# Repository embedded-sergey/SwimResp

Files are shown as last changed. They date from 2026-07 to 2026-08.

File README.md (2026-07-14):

# SwimResp
SwimResp is a pump and motor speed controller for swim tunnels used to perform Ucrit measurements.  It also interfaces with the PyroScience Pico‑OEM module to transmit optical dissolved‑oxygen and temperature data over USB to a PC for logging during intermittent‑flow aquatic respirometry workflows.

It is part of the FishResp project (more information at https://fishresp.org).

## Build Guide
The complete assembly, wiring, calibration, and safety instructions are provided in: `docs/SwimResp_Build_Guide.md`

This README intentionally avoids duplicating the Build Guide.

## Licensing
SwimResp uses a multi‑license structure:

- **Hardware designs:** CERN‑OHL‑S v2  
- **Software:** GPL‑3.0  
- **Documentation:** CC‑BY‑4.0  

Mixed‑content files (e.g., documentation containing schematics or code snippets) are governed by the license of each component.

See the **LICENSE** file for the human‑readable overview and the `LICENSES/` directory for full legal texts.

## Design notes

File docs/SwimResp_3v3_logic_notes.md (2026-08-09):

# SwimResp 3.3 V‑logic notes  
SwimResp can operate with 3.3 V‑logic Nano‑family boards (Nano 33 BLE, Nano 33 IoT, RP2040, Nano ESP32), which may provide additional functionality.

This topic is outside the scope of the main build guide. Several design and assembly adjustments are required, and the list below reflects unverified considerations only.

1. All SwimResp components (status LED, push button, L298N motor driver board, OLED display, Pico‑O2 OEM logger) operate correctly at 3.3 V logic level.

2. Power the OLED display from the 3.3 V pin of a 3.3 V‑logic Arduino Nano to ensure reliable two‑way I²C communication.

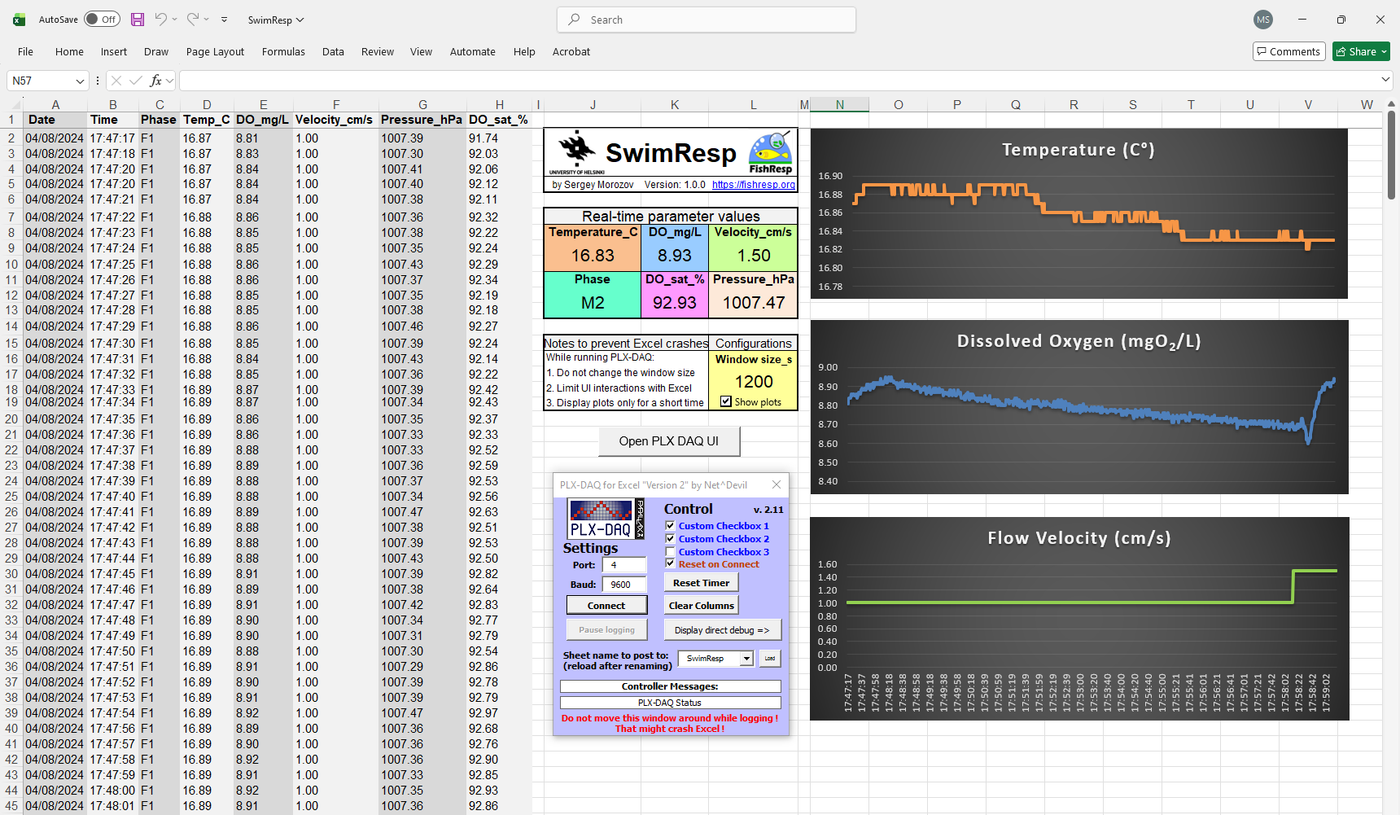
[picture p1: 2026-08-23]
docs/images/SwimResp_screenshot.png

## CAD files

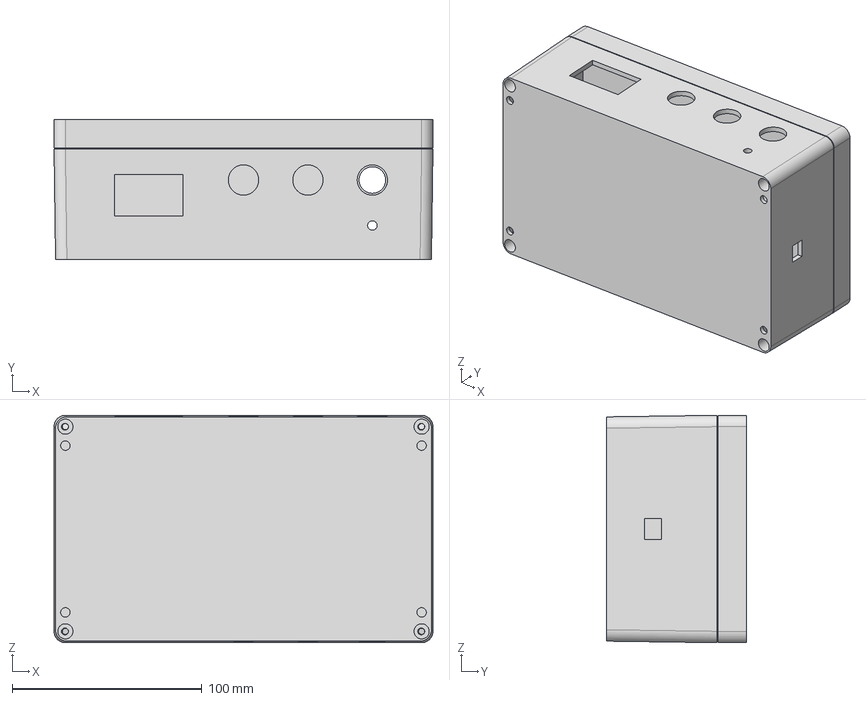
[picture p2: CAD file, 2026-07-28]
hardware/cad/SwimResp_enclosure_assembly.step
200.0 x 74.0 x 120.0 mm

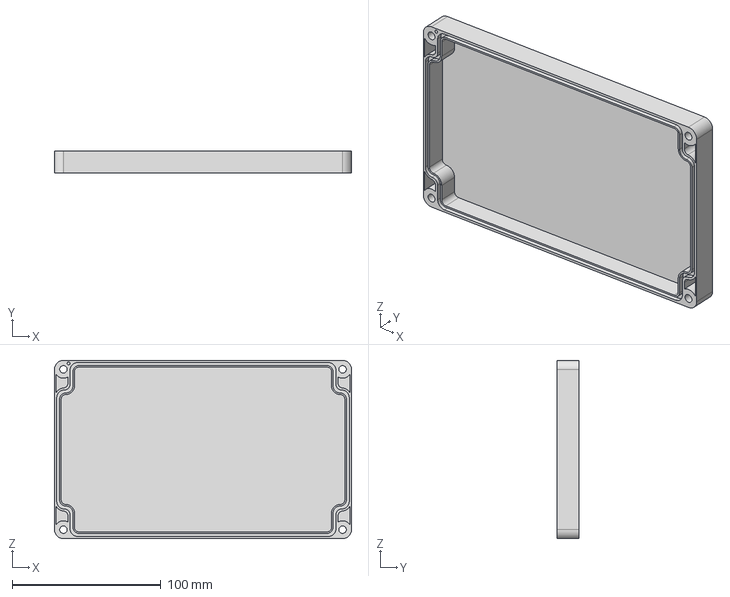
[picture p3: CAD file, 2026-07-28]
hardware/cad/SwimResp_enclosure_cover.step
200.0 x 15.0 x 120.0 mm

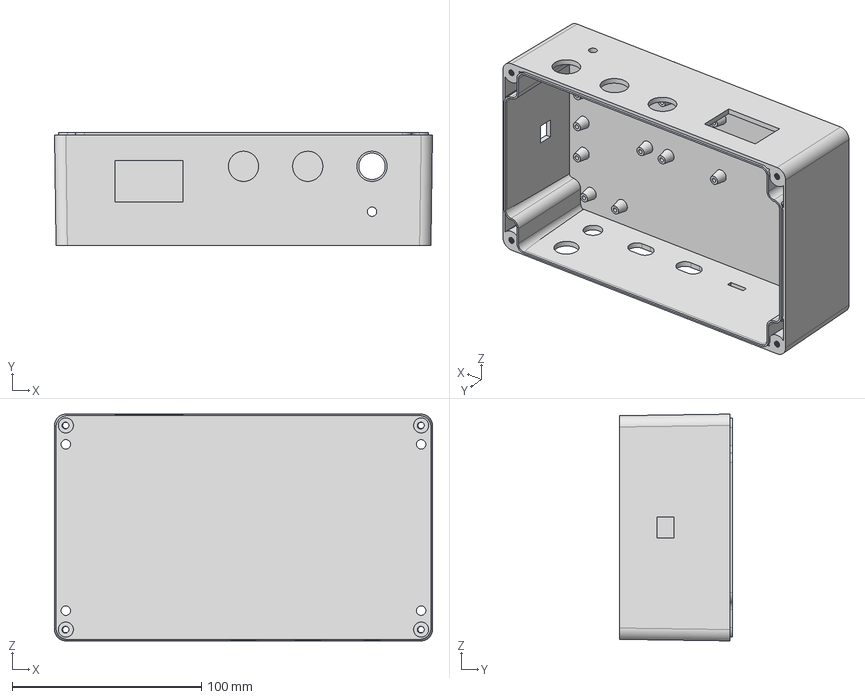
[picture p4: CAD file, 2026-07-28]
hardware/cad/SwimResp_enclosure_base.step
200.0 x 60.0 x 120.0 mm

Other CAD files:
hardware/stl/SwimResp_enclosure_base.stl
hardware/stl/SwimResp_enclosure_cover.stl

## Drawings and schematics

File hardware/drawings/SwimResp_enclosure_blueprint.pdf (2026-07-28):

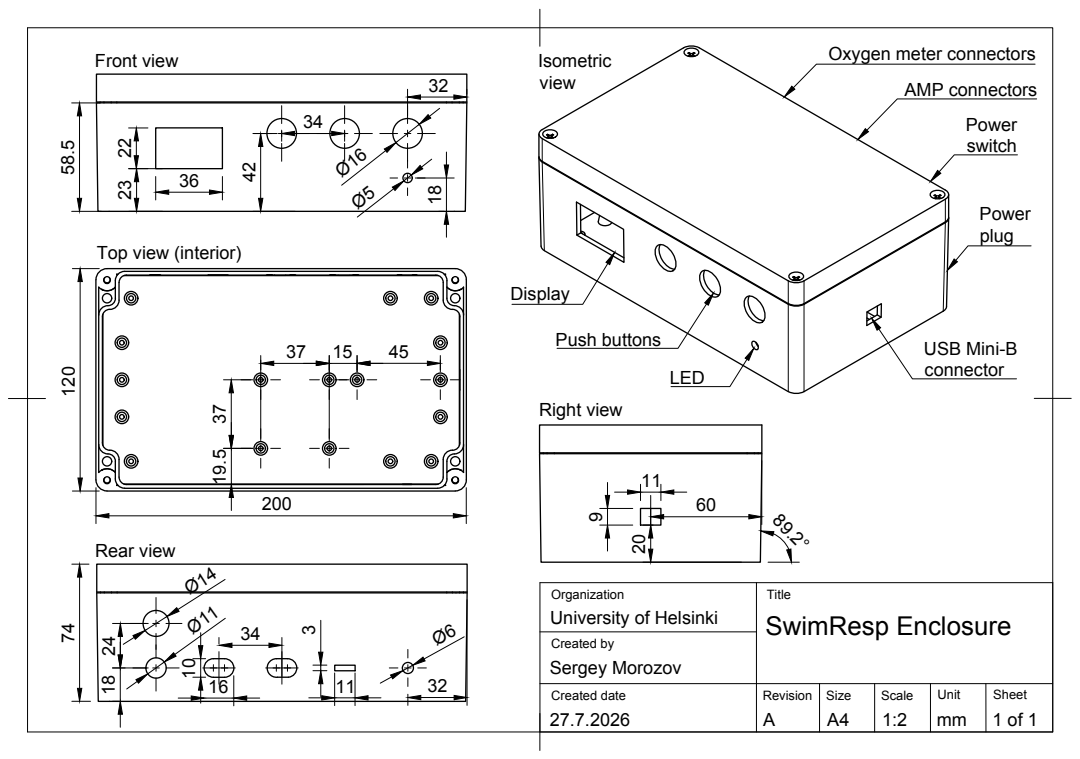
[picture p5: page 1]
Created by; Created date; Revision; Size; Scale; SwimResp Enclosure; Sergey Morozov; USB Mini-B; Push buttons; AMP connectors; Rear view; Right view

Oxygen meter connectors Front view

Top view (interior)

University of Helsinki

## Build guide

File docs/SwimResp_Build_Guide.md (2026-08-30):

---
title: "SwimResp Build Guide"
author: "Sergey Morozov"
date: "30 August 2026"
revision: "0.6"
toc: true
toc-depth: 3
---

# SwimResp Build Guide
**Revision:** 0.6
**Author:** Sergey Morozov  
**Date:** 30 August 2026

<!-- begin-md-image -->
SwimResp Device
<!-- end-md-image -->

# Table of Contents

1. [Introduction](#1-introduction)
2. [Safety Notes](#2-safety-notes)  
   2.1 [Environmental Safety](#21-environmental-safety)  
   2.2 [Electrical Safety](#22-electrical-safety)  
   2.3 [Mechanical and Tool Safety](#23-mechanical-and-tool-safety)
3. [Bill of Materials](#3-bill-of-materials)
4. [Tools and Consumables](#4-tools-and-consumables)
5. [Assembly Instructions](#5-assembly-instructions)  
   5.1 [Preparing the enclosure](#51-preparing-the-enclosure)  
   5.2 [Installing power distribution components](#52-installing-power-distribution-components)  
   5.3 [Installing and wiring the controller](#53-installing-and-wiring-the-controller)  
   5.4 [Adding the user interface components](#54-adding-the-user-interface-components)  
   5.5 [Connecting the DO and temperature logger](#55-connecting-the-do-and-temperature-logger)  
   5.6 [Finalizing the enclosure](#56-finalizing-the-enclosure)
6. [Software Setup](#6-software-setup)   
   6.1 [Installing the Arduino IDE and uploading firmware](#61-installing-the-arduino-ide-and-uploading-firmware)   
   6.2 [Configuring the data‑logging software](#62-configuring-the-data‑logging-software)   
   6.3 [Establishing the serial connection and recording data](#63-establishing-the-serial-connection-and-recording-data)    
   6.4 [Exporting and managing recorded data](#65-exporting-and-managing-recorded-data)
7. [Functional Testing and Verification](#7-functional-testing-and-verification)
8. [Appendices](#8-appendices)
---

# 1. Introduction

SwimResp is an open‑source device for controlling a 12 V DC pump and motor used in a DIY swim tunnel. It controls water‑flow speed inside the swim tunnel, refreshes water via a pump, and displays operational data on a local screen. The device is designed to interface with the dissolved‑oxygen meter Pico‑O2‑OEM, enabling threshold‑based pump activation in addition to simple time‑based control. All dissolved‑oxygen and temperature data fetched from the Pico‑O2‑OEM are transmitted to a PC for real‑time visualization together with water‑flow speed and pump‑phase information.

This guide explains how to assemble the hardware step by step. It covers preparing the enclosure, wiring the electronics, installing the user‑interface components, and loading the software. The document focuses strictly on construction and verification; experimental applications and biological context are described separately in the accompanying manuscript.

**User skill level.** The build guide is intended for students, technicians, and researchers with basic technical skills. No engineering background is required. Users should be comfortable with simple soldering and basic multimeter measurements (continuity and DC voltage).

**Assembly environment.** SwimResp can be assembled in any standard workspace equipped for basic electronics and mechanical tasks, including university or biological‑station workshops, applied‑sciences laboratories, or local FabLabs (a global directory is provided by the Fab Foundation). The enclosure can be purchased and modified or fabricated using a 3D printer.

**Estimated build time.** Assembly, software setup, and full functional verification typically require 1–2 days for a first‑time build depending on user skills. When assembling multiple identical units, the per‑device time decreases substantially as enclosure preparation and wiring become more routine.

## Versioning

This guide corresponds to SwimResp hardware, software, and documentation release **v1.0.0**.

Source files and updates are available in the public repository:  
<https://github.com/embedded-sergey/SwimResp>

## Licensing

- **Software:** GPL‑3.0  
- **Hardware designs:** CERN-OHL-S v2 
- **Documentation (including this guide):** CC‑BY‑4.0  

These licenses ensure open access, modifiability, and reproducibility across all components of the SwimResp platform. If this guide contains hardware diagrams or code snippets, those components are licensed under their respective hardware or software licenses.

# 2. Safety Notes

## 2.1 Environmental Safety

SwimResp is designed to be water-resistant, providing protection against accidental splashes and operation in high humidity environments. To reduce moisture accumulation in humid environment, place an absorbent pack inside the enclosure. SwimResp is not waterproof: if the device is submerged or dropped into the water, immediately power it off, disconnect the USB cable and do not resume operation until the enclosure and internal components have been thoroughly inspected and dried.

## 2.2 Electrical Safety

SwimResp operates at 5-12 VDC, which falls within the extra-low-voltage category recognized in electrical safety standards worldwide. Devices operating at ≤ 24 VDC are generally considered safe for personal, educational, and research use, and in most countries can be built and used without electrical certification, provided that a certified external power supply is used and no mains‑voltage wiring is modified. 

The power supply unit must include integrated overcurrent protection (fuse or electronic limit) and should be selected based on the total power requirements of the connected pump and motor. For example, if a pump and a motor draw 0.6 A each at 12 V, the total current is 1.2 A. In this case, a 12 V, 2 A power supply provides sufficient overhead for safe operation (i.e., operating below ~70% of the power supply unit's maximum rated output). The minimum recommended wire size for regular 5-12V is 24 AWG and 20 AWG for high‑current pump circuits.

During assembly and testing, follow basic electrical‑safety practices. Keep the device disconnected from any power source while you work. Check the polarity of every wire before connecting power, and avoid any contact between the positive and negative lines. Before turning the device on, inspect all solder joints, connectors, and insulation to make sure nothing is loose or exposed. Use a multimeter to check your wiring: confirm that each connection has continuity and make sure there are no accidental shorts. Switch the device on only when you’re sure all connections are correct.

## 2.3 Mechanical and Tool Safety

Use adhesive materials, mechanical and electrical tools listed in the section "Tools and Consumables” with care. If you are inexperienced with some of them, seek assistance from a trained technician. Wear personal protection equipment: protective glasses and fume mask, especially when soldering and use heat‑resistant mat to protect your workspace. During the assembly process run the tests referred in the assembly instructions to make the assembly process to be safe and verify the quality of SwimResp.

# 3. Bill of Materials

Price estimates for generic components use Amazon.com  as a reference, based on pricing available in August 2026. Amazon is chosen because it provides broad international availability, relatively stable pricing, and consistent product listings, which makes it a practical baseline for reproducible cost estimates. Because many components on Amazon are sold only in bulk packs, the bill of materials lists the price of the entire pack even when only one piece is needed, which inflates the apparent cost of a single device and results in unnecessary surplus. In practice, individual components can often be purchased at lower cost from suppliers that support small‑quantity or single‑unit purchasing, including local electronics stores, online marketplaces, and global engineering distributors such as Mouser or Digi‑Key. Prices for specialized sensors and measurement devices are taken directly from manufacturers’ websites when these items are not consistently available through the above distributors.

Prices listed in this BOM exclude VAT, customs duties, and delivery costs.

| Part Name | Manufacturer | Quantity | Unit Price (USD)¹ | Total Price (USD) | Notes |
|---|---|---|---|---|---|
| Industrial ABS enclosure, IP65, 200×120×75 mm | Generic | 1 pc | 10 | 10 | – |
| Male waterproof automotive connectors (Superseal 1.5‑style), 2‑pin | Generic | 2 male–female pairs | 8 | 8 | Bulk pack (3–5 pairs). Female connectors are also needed for a pump and a motor connected to SwimResp² |
| L298N motor driver board | Generic | 1 pc | 5 |  5 | Supports one pump and one motor at up to ~1.5 A per channel (2 A peak) at 12 V. |
| Red and black wires, 20 AWG | Generic | 1 m each | 3 | 3 | Use 16 AWG for high‑current pumps and motors |
| Round rocker switch, mounting hole diameter 15 mm, 2-pin | Generic | 1 pc | 6 | 6 | Bulk pack (3–5 pcs) |
| DC power jack, steel, 5.5×2.1 mm | Generic | 1 pc | 7 | 7 | Bulk pack (3–5 pcs) |
| Arduino Nano–compatible board (ATmega328P) with Mini-B USB cable and screw‑terminal adapter | Generic | 1 kit | 9 | 9 | The board can be replaced by the Arduino Nano rev.3 or 3.3 V-board from Nano family³ |
| Push button, mounting hole diameter 16 mm, 2-pin | Generic | 3 pcs | 10 | 10 | Bulk pack (10-24 pcs) |
| LED, 5 mm | Generic | 1 pc | 6 | 6 | Bulk pack (50–200 pcs) |
| Resistor, 220 Ω, ¼ W | Generic | 1 pc | 6 | 6 | Bulk pack (20–200 pcs) |
| 1.3" OLED 128x64 I²C monochrome display, Driver chip: SH1106, 3.3–5 V | Generic | 1 pc | 9 | 9 | - |
| Solderless breadboard BB170, 47x35x8.5 mm | Generic | 1 pc | 6 | 6 | Bulk pack (3–6 pcs) |
| Female to male jumper wires, square jumpers, 10 cm | Generic | 1 kit | 5 | 5 | – |
| M3 Hex spacers standoff kit | Generic | 1 kit | 12 | 12 | To attach terminal and motor driver boards to enclosure | 
| Optical oxygen meter Pico‑02 OEM module, UART, 3.3–5 V | PyroScience | 1 pc | NA⁴ | NA⁴ | Compatible with optical REDFLASH oxygen sensors and PT100 |

**Grand total: 102 USD excluding price for Pico oxygen meter**.²˒⁴

*¹ Unit prices reflect the smallest purchasable quantity on Amazon.com. When only bulk packs are available, the listed price corresponds to the full pack even if a single piece is required.*

*² This BOM does not include probes, pumps, motors or their cables.*

*³ This guide does not cover 3.3 V‑logic operation; refer to [SwimResp_3v3_logic_notes.md](SwimResp_3v3_logic_notes.md) for the necessary compatibility adjustments.*

*⁴ Price available only via manufacturer quotation.*

# 4. Tools and Consumables
These items are not included in the BOM because they are general workshop supplies rather than project‑specific components, but they are still required for assembly. Most of the tools and consumables can be found in FabLabs, electronic/robotics clubs and Universities of Applied Sciences around the world.

Mechanical tools:
* utility cutter
* long-nose pliers
* wire cutters
* screwdriver
* drill with step drill bit
* rotary tool with 1 mm drill bit and cut‑off wheel

Electrical tools and materials:
* soldering iron
* solder wire
* flux
* heat-shrink tubing

Adhesives:
* hot-glue gun
* hot-glue sticks
* superglue
* silicone tape

Measuring and marking tools:
* multimeter
* ruler
* pencil

Safety tools:
* protective glasses
* fume mask
* heat-resistant mat

# 5. Assembly Instructions
This section contains 40 assembly steps covering mechanical preparation, wiring, and installation of all the components. Before beginning the assembly, note that several steps in Sections 5 and 6 have corresponding functional checks in Section 7. These checks can be performed immediately after completing each relevant assembly step or after the full assembly is finished. Performing the checks in parallel with assembly helps identify wiring mistakes early and reduces the risk of component damage.

## 5.1 Preparing the enclosure
SwimResp can be assembled using either a commercially available enclosure or the provided 3D‑printed enclosure. The printed version already includes all openings for the switch, power jack, and display, so drilling and cutting are not required (Steps 2–7). STL files are available in the SwimResp repository.

**Step 1.** Unscrew the cover to open the enclosure.

**Step 2.** Mark the hole positions on the base and on the cover of the enclosure using a ruler and a pencil, following the dimensions shown in Figure 1.

Figure 1. Blueprint of the SwimResp enclosure  
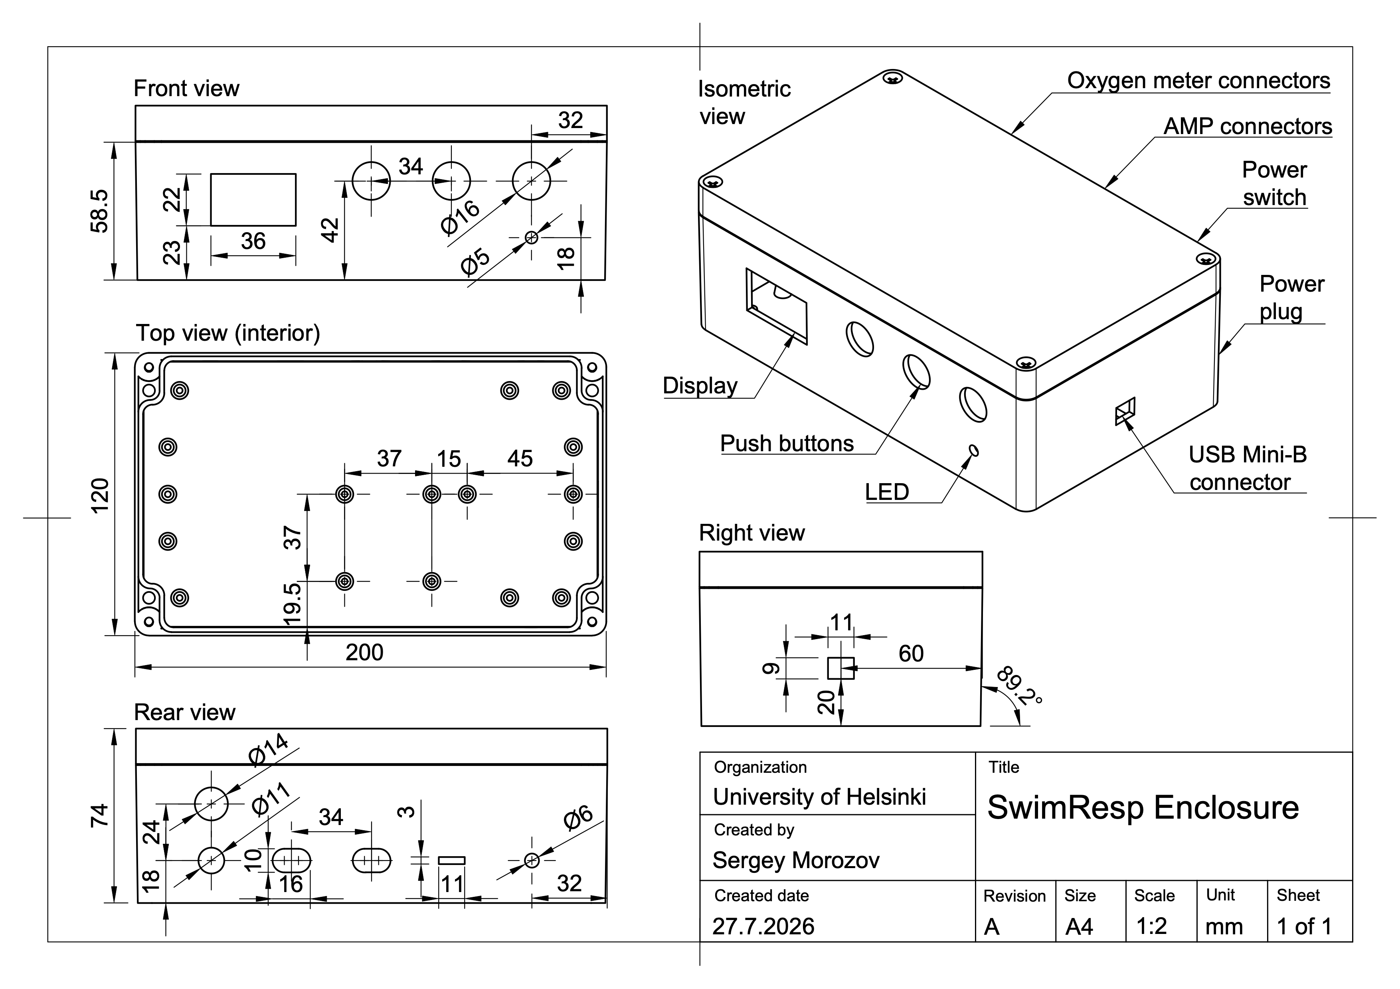
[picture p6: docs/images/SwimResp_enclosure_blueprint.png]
SwimResp enclosure blueprint


**Step 3.** If you use components with different form factors or an enclosure with different dimensions, adjust the blueprint. Alternatively, mark the hole positions directly on the enclosure if dimensions differ.

**Step 4.** Drill the holes at the marked positions, then refine their shape using a utility cutter if needed.

**Step 5.** Cut the recess for the OLED display using either a utility cutter guided along a ruler or a rotary tool with a cut‑off wheel.

**Step 6.** For oval‑shaped holes on the rear panel, drill two overlapping holes and shape the opening with a cutter or a rotary tool, including the top recess.

**Step 7.** Place five M3 hex standoffs at the positions shown in the top interior view of Figure 1 and temporarily position the screw terminal adapter and the L298N motor driver board against them to verify alignment. Once correct alignment is confirmed, glue the M3 hex standoffs to the enclosure at the identified positions using superglue.

**Step 8.** Remove the two protrusions on the bottom side of each body of a male waterproof connector using a utility cutter or a rotary tool with a cut‑off wheel.

**Step 9.** Assemble one male waterproof connector with 15 cm wires and the other one with 5 cm wires. Ensure that the red wire is inserted into port 1 of the connector and the black wire into port 2, respectively. Incorrect color order can lead to wiring errors.

**Step 10.** Insert the male waterproof connector with 15 cm wires into the oval‑shaped hole in the middle of the rear panel, and insert the second connector into the remaining oval‑shaped hole. Secure both connectors to the enclosure wall using a hot‑glue gun.

## 5.2 Installing power distribution components
**Step 11.** Mount the L298N motor driver board onto the standoffs on the bottom panel of the enclosure and screw it in place.

**Step 12.** Connect the wires from the middle male waterproof connector to OUT1 and OUT2, and the wires from the second waterproof connector to OUT3 and OUT4 of the L298N motor driver board, respectively, as shown in Figure 2.

Figure 2. Wiring scheme of the SwimResp
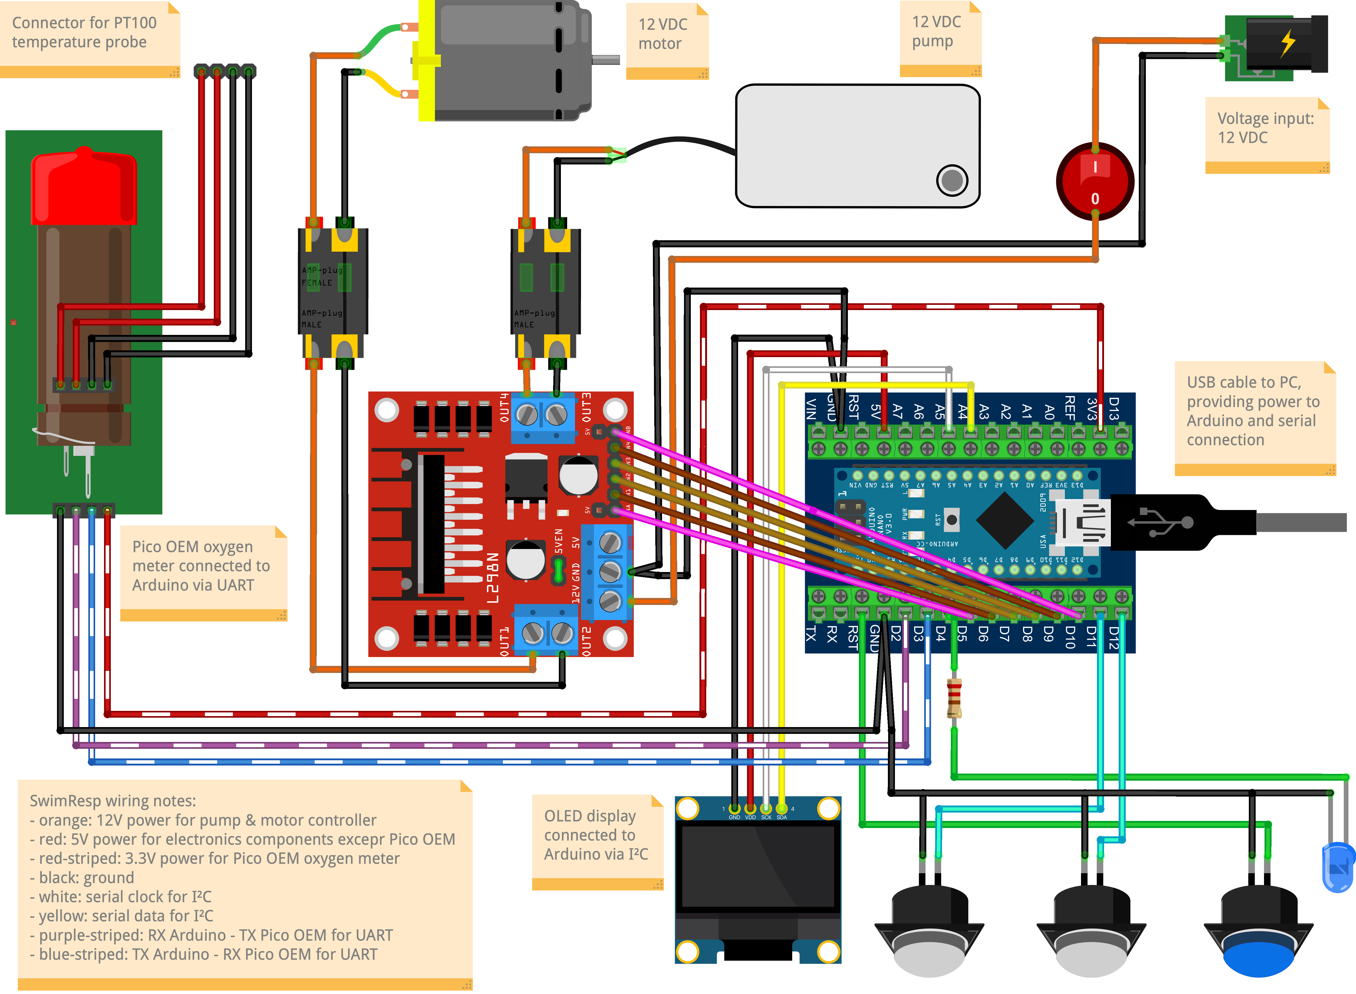
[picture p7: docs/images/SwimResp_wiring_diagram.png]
Wiring scheme of the SwimResp


**Step 13.** Mount the rocker power switch and the power connector to the rear panel of the enclosure.

**Step 14.** Solder the shortest red wire (shown in Figure 3) to the power pin of the power connector and the lower pin of the power switch.

**Step 15.** Solder the 15 cm black wire (shown in Figure 3) to the ground pin of the power connector and insulate the joint with heat‑shrink tubing. Attach the other end of this wire to the terminal block leading to the GND pin of the L298N motor driver board (see Figure 2).

**Step 16.** Solder the 15 cm red wire (shown in Figure 3) to the upper pin of the power switch. Attach the other end of this wire to the terminal block leading to the 12 V pin of the L298N motor driver board (see Figure 2).

## 5.3 Installing and wiring the controller
**Step 17.** Prepare the wire jumpers and wires needed for the device assembly, as shown in Figure 3, using wire cutters.

**Step 18.** Mount the Arduino Nano screw‑terminal adapter onto the standoffs on the bottom panel of the enclosure and screw it in place. Ensure that the D12 and D13 labels are oriented towards the USB opening on the side panel. For cleaner wire organisation, route the red and black power wires behind the adapter.

**Step 19.** Install the Arduino Nano–compatible board (ATmega328P) into the screw‑terminal adapter. Check that the Arduino Nano’s D12 pin aligns with the adapter’s D12 terminal.

**Step 20.** Connect six jumper wires to the L298N motor driver board (ENA, IN1, IN2, IN3, IN4, ENB) and secure the free wire ends in the screw‑terminal adapter (the pins D5-D10, respectively) as shown in Figure 2.

## 5.4 Adding the user interface components
**Step 21.** Solder the LED together with the 220 Ω resistor and the wires as shown in Figure 3. Ensure correct LED polarity (long leg is typically +).

**Step 22.** Mount the LED into the corresponding opening on the front panel of the enclosure using a hot‑glue gun.

**Step 23.** Connect the LED’s wire with the resistor to the D4 pin of the screw‑terminal adapter as shown in Figure 2.

**Step 24.** Install three push buttons on the front panel using their mounting nuts.

**Step 25.** Solder black ground wires in a daisy‑chain manner from the LED to each push button, and connect the last one to the GND pin of the screw‑terminal adapter (Figure 2).

**Step 26.** Solder the green wires from each button to the corresponding pins of the screw‑terminal adapter shown in Figure 2 (see [Check 5](#check-5-no-wiring-faults-in-the-lowvoltage-control-circuit)).

**Step 27.** Secure the OLED display with hot glue around its edges on both sides of the enclosure (Figure 1). Apply glue only to PCB edges, not the glass.

**Step 28.** Connect the OLED display to the corresponding pins of the screw‑terminal adapter using 20 cm wire jumpers, as shown in Figure 2 and Figure 5. Note that pins GND and VCC can be swapped on some OLED modules; check the silkscreen and adjust wiring accordingly.

Figure 5. Final assembly photo.

Ensure to twist the I²C wires (data and clock) together whenever routing I²C lines inside the enclosure (Figure 5).

## 5.5 Connecting the DO and temperature logger
**Step 29.** Prepare four 10 cm female jumper wires using wire cutters as shown in Figure 3. Glue the jumper heads together to form a four‑pin female connector, so they remain aligned when inserted into the enclosure.

**Step 30.** Insert the connector into the rectangular opening and secure it to the enclosure wall using a hot‑glue gun (Figure 1, Figure 2).

**Step 31.** Solder the other wire ends to the solder pads for the external temperature sensor on the Pico-O2 logger as shown in Figure 2. Use minimal solder to avoid bridging pads.

**Step 32.** Mount the Pico-O2 logger to the rear panel of the enclosure (Figure 5).

**Step 33.** Insert 20 cm wires into the Connector X1 of the Pico‑O2 logger, as shown in Figure 2. Note that the embedded LED is located above the Connector X1 for the correct orientation.

**Step 34.** Connect the other wire ends to the corresponding pins of the screw‑terminal adapter (Figure 2).

**Step 35.** Optionally, glue the solderless breadboard to the bottom part of the enclosure between the Pico‑O2 logger and the L298N motor driver board. This breadboard can be used for integrating new components (SwimResp modifications or enhancements).

## 5.5 Finalizing the enclosure
**Step 36.** Insert the provided insulating material into the enclosure groove to prevent water contact between the environment and internal wiring.

**Step 37.** Fabricate a water-resistant layer that is attached to the USB cable connected to the Arduino Nano–compatible board (ATmega328P). This must fit the opening on the cover of the enclosure and can be made from silicone tape or another flexible waterproof material.

**Step 38.** Fabricate an additional water‑resistant lid to seal the opening during storage or when the USB cable is removed.

**Step 39.** Screw the cover securely to the base using the original mounting screws.

**Step 40.** Ensure the cover is seated evenly and that no wires are pinched when closing the enclosure.

# 6. Software Setup
This section describes how to program the Arduino Nano and configure the software required to record data from SwimResp. The workflow below reflects the configuration tested and validated for this build.

## 6.1 Configuring the data‑logging software
SwimResp was validated on Windows 10 using Microsoft Excel together with PLX-DAQ-2, an Excel-based serial data logger. This combination provides a straightforward installation process, stable serial communication, direct data logging, and real‑time plotting.

Install Microsoft Excel (version 2016 or newer) if it is not already available on your system. Download PLX‑DAQ‑2 version 2.11 from its original source: https://forum.arduino.cc/t/plx-daq-version-2-now-with-64-bit-support-and-further-new-features/420628. 

SwimResp includes a macro‑free Excel template (SwimResp_template.xlsx) containing recommended column names, formatting, and real‑time plots. This template is used together with PLX‑DAQ‑2 as described in Section 6.4.

Note that PLX‑DAQ‑2 is available only for Windows. Users working on macOS or Linux may employ alternative serial‑logging tools such as CoolTerm or Python with the PySerial library; however, these alternatives were not validated during development and are not covered in this guide.

## 6.2 Preparing the SwimResp Excel Environment
Since PLX‑DAQ‑2 cannot be redistributed after modification and does not include the SwimResp worksheet, users should set up the SwimResp environment locally. The setup is a simple, one‑time, five‑step process and requires no programming skills.

1. Unblock both PLX‑DAQ‑2.xlsm and SwimResp_template.xlsm because Windows blocks downloaded Excel macro files. Right‑click the .xlsm file, select 'Properties', tick 'Unblock' and press the 'Apply' button. In addition, "Enable Macros" / "Enable Content" in the pop-up message when Excel has been opened.

2. Copy the 'SwimResp' sheet into PLX‑DAQ‑2.xlsm. Open both PLX‑DAQ‑2.xlsm and SwimResp_template.xlsm, right‑click the SwimResp sheet tab, select "Move or Copy…" and select PLX‑DAQ‑2.xlsm, press OK. Close SwimResp_template.xlsm without saving.

3. Assign the Plotting macro. In PLX‑DAQ‑2.xlsm, right‑click the "Show Plots" checkbox, select "Assign Macro…", choose "Sheet2.ShowPlotCheckBox", and press OK.

4. Delete all sheets except SwimResp. Remove all other sheets in PLX‑DAQ‑2.xlsm so that only the SwimResp sheet remains.

5. Save the file PLX‑DAQ‑2.xlsm in Excel, close it and rename to SwimResp.xlsm.

Keep a backup copy of the assembled SwimResp.xlsm outside your experiment folders. If the file is lost or overwritten, it must be rebuilt using the steps in Section 6.2.

## 6.3 Installing the Arduino IDE and uploading firmware
SwimResp uses an Arduino Nano microcontroller (original or clone). To load the firmware:

1. Install Arduino IDE 2.0 or later from the official Arduino website.

2. Open the provided SwimResp.ino firmware file in the Arduino IDE.

3. Connect the Arduino Nano to your PC via USB.

4. In Tools → Board, select Arduino Nano.

5. In Tools → Processor, select ATmega328P (Old Bootloader) if you are using a common Nano clone.

6. In Tools → Port, select the COM port used by the Arduino Nano.

7. Install the SSD1306Ascii display library:
    - Open Sketch → Include Library → Manage Libraries…
    - Search for SSD1306Ascii
    - Click Install

8. Adjust the variable values in the USER INTERFACE section of the firmware according to your experimental design.

9. Click Upload (left‑arrow icon below the menu bar) to flash the firmware to the board. If the output panel shows no errors, you may close the Arduino IDE.

After uploading, the Arduino Nano will begin sending serial data over USB to PC (see [Check 6](#check-6-controlling-pumps-by-arduino-code)).

## 6.4 Establishing the serial connection and recording data
Open the SwimResp.xlsm file and click on "Open PLX DAQ UI" button there if it is not popped up automatically.

1. In the PLX‑DAQ‑2 control panel, select the serial port (COM number) corresponding to the connected Arduino Nano. 

2. Click Connect to open the serial port, initialize communication, and begin writing incoming data directly into the spreadsheet.

3. For improved performance and stability during long recordings, untick "Show plots" and minimize the PLX‑DAQ‑2 control window while data collection is in progress. 

4. Note that editing the Excel sheet during the data collection might break the serial connection and Excel will be relaunched.

## 6.5 Exporting and managing recorded data
When data collection is complete, press Disconnect in the PLX‑DAQ‑2 control panel to close the serial connection. The recorded data remain in the spreadsheet and should be saved at this stage. Export the dataset either as a standard Excel workbook (.xlsx) or as a comma‑separated values file (.csv) for downstream analysis. If the Connect button is pressed again before exporting, the spreadsheet will be cleared and new data will overwrite the previous session. Always save or export the data before reconnecting to avoid accidental data loss (see [Check 7](#check-7-verifying-serial-communication-and-data-logging)).

After completing all assembly and software steps, perform the full‑system validation described in [Check 8](#check-8-full-system-test-with-submerged-pumps-and-currentdraw-safety).

For reproducibility, store the SwimResp.ino file used for the experiment together with the SwimResp.xlsm dataset or exported .csv file.

# 7. Functional Testing and Verification
WIP

# 8. Appendices

Appendix 1: Schematics of SwimResp
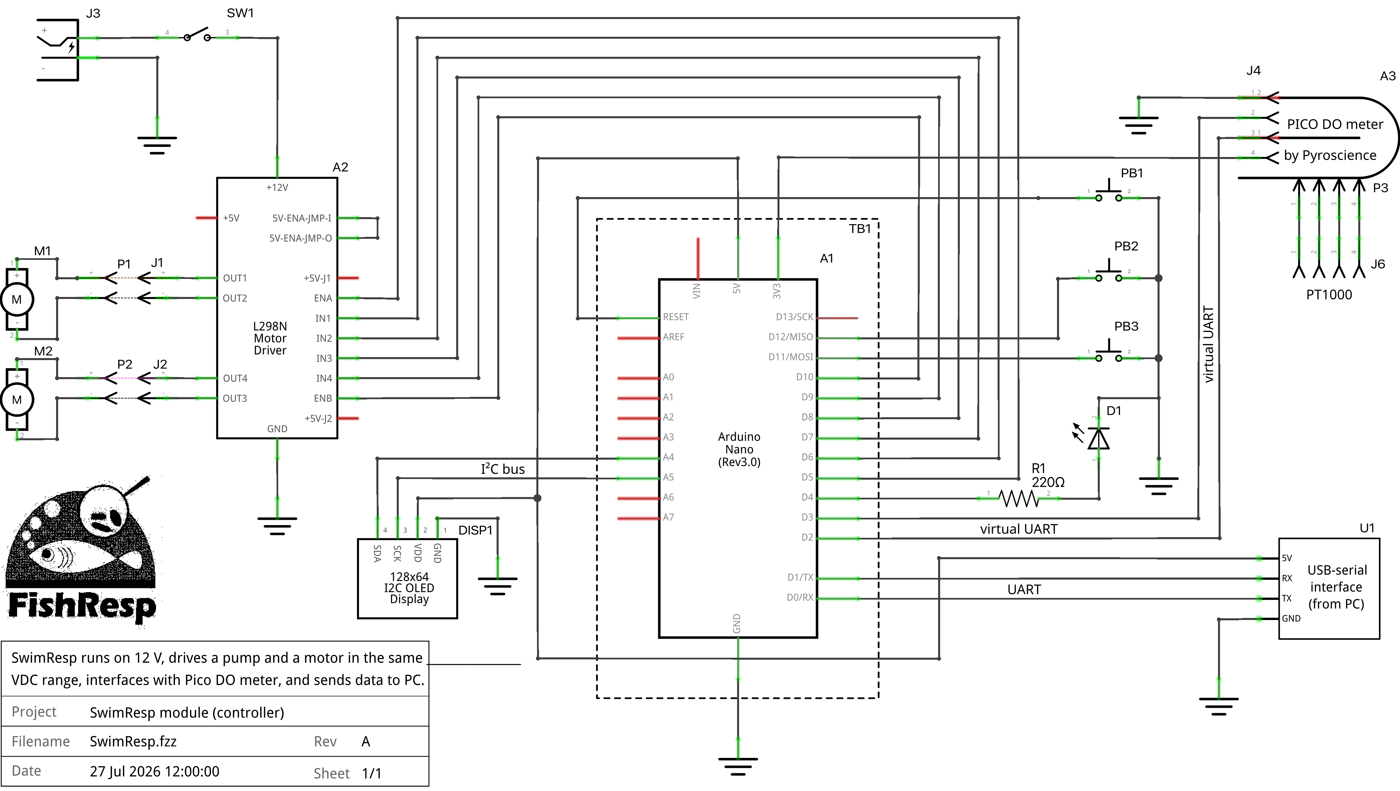
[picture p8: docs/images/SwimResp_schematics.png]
Schematics of SwimResp


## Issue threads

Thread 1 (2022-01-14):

Create a reverse function for a button

embedded-sergey, 2022-01-14:

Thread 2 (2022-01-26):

Add a code for the motor control button

embedded-sergey, 2022-01-26:
Short-tem mode:
    If the button has been pushed for less than 1 sec:
    - smoothly reverse the direction of the motor rotation
    - increase the motor speed till the initial speed before the button was pressed
    - keep this speed for N seconds
    - smoothly reverse the motor rotation back
    - increase the motor speed to the initial speed before the button was pressed.

Long-term mode:
    If the button was pressed for 3 sec or more:
    - reduce the motor speed to the base level of the Ucrit protocol
    - keep it at the base level till the end of the experiment.

embedded-sergey, 2022-01-26:
Pins A6 and A7 of Arduino Nano do not have pull-up resistors and can be used only for analog I/O, thus two additional 10k resistors are required. Luckily, A6 and A7 can still be used for buttons, need to [check it](https://www.reddit.com/r/arduino/comments/gikxe1/arduino_nano_use_a6_and_a7_to_read_button_presses/).

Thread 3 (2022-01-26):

Add voltage values and round bits to the motor output

embedded-sergey, 2022-01-26:
Convert bits 0...255 to voltage depending on the voltage of the motor(s). It means that we need an extra variable in the user interface, by default 12V, but can be any integer number from 5 to 36 (the maximum allowed voltage by the motor driver L298n)

Closed 2024-04-26.

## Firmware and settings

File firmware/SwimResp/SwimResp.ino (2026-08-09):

////////////////////
// USER INTERFACE //
////////////////////

// Type which method for switching between flush and measurement phases: 
// i.e. uncomment one of the two options below i.e (by default OPTION 1).

// OPTION 1: Set the constant measurement and flush phase periods (in seconds)
// String PHASE_SWITCH_METHOD = "constant_phase_period"; // (UN)COMMENT THIS LINE!
unsigned long FLUSH = 60;
unsigned long MEASUREMENT = 240;

// OPTION 2: Choose the % air saturation high threshold for DO to start 
//           measurement phase and low threshold to start flushing the tunnel
String PHASE_SWITCH_METHOD = "saturation_threshold"; // (UN)COMMENT THIS LINE!
const float LOW_SATURATION_THRESHOLD = 75;  // to trigger the flush pump ON
const float HIGH_SATURATION_THRESHOLD = 90;  // to trigger the flush pump OFF


// Flow velocity (in cm/s) and length (in seconds) of increment steps
// of the Ucrit protocol (typically, the have similar length)
float VELOCITY[] = {2.0, 2.5, 3.0, 3.5, 4.0, 4.5, 5.0, 5.5, 6.0};

unsigned int LENGTH[] = {300, 300, 300, 300, 300, 300, 300, 300, 300};

// Motor calibration
// Record the flow of die solution or neutrally buoyant particlesa using a 
// slow-motion camera at one motor speed starting from lowest posssible.
// Calculate flow velocity based on your record and add it in  the arrays 
// below with the corresponding PWM value for that  motor speed (0...255). 
// Repeat the process with other motor speeds to get at least three reference
//  points for motor calibration (more reference points -> better precision).

// Note that the values in an array must ascend progressively!
float in[]  = {0.8, 1.2, 3.2, 3.7, 4.3, 6.2}; // flow velocity in cm/s
float out[] = {15, 18, 25, 40, 80, 225}; // raw data: 0...255



/////////////////////////
// IMPLEMENTATION CODE //
/////////////////////////
#include <SoftwareSerial.h>
#include "SSD1306Ascii.h"
#include "SSD1306AsciiAvrI2c.h"

// pinout map
const byte PICO_RX = 2; // DO meter
const byte PICO_TX = 3; // DO meter
const byte LED = 4;
const byte enA = 5; // PWM for a motor
const byte in1 = 6; // motor
const byte in2 = 7; // motor
const byte in3 = 8; // pump
const byte in4 = 9; // pump
const byte enB = 10; // PWM for a pump
const byte BUTTON_GREEN = 11;
const byte BUTTON_RED = 12;
const byte I2C_CLOCK = A4; // display
const byte I2C_DATA = A5; // display

// display
#define I2C_ADDRESS 0x3C
#define RST_PIN -1
SSD1306AsciiAvrI2c oled;
unsigned long previousTime_display = 0;

// DO logger
SoftwareSerial mySerial(PICO_RX, PICO_TX); // RX, TX
char charArr[255];
char *strings[25];
char *ptr = NULL;
unsigned long previousTime_logger = 0;
float DO;
float SATURATION;
float TEMPERATURE;
float PRESSURE;
bool HIGH_SATURATION_REACHED = true; // flag to know when to stop flushing

// buttons
long buttonTimer = 0;
long buttonTime = 1000;
boolean buttonActive = false;
boolean longPressActive = false;
boolean button1Active = false;
boolean button2Active = false;
boolean reverseMotor1 = false; //motor IN1
boolean reverseMotor2 = true; //motor IN2

// motor & pump
int PERIOD = 1;
float TIMER;
int i = 0;
String PHASE = "M0", F, M, f = "F", m = "M";
unsigned long previousTime_pump = 0;
unsigned long previousTime_motor = 0;

// For autosaving
unsigned long lastSave;


void setup(){
  // Display
  #if RST_PIN >= 0
  oled.begin(&Adafruit128x64, I2C_ADDRESS, RST_PIN);
  #else // RST_PIN >= 0
  oled.begin(&Adafruit128x64, I2C_ADDRESS);
  #endif // RST_PIN >= 0
  oled.clear();
  oled.setFont(Adafruit5x7);

  // Button setup
  pinMode(BUTTON_GREEN, INPUT_PULLUP);
  pinMode(BUTTON_RED, INPUT_PULLUP);
  
  // LED for a pump
  pinMode(LED, OUTPUT);

  // Set all the motor control pins to outputs
  pinMode(enA, OUTPUT);
  pinMode(enB, OUTPUT);
  pinMode(in1, OUTPUT);
  pinMode(in2, OUTPUT);
  pinMode(in3, OUTPUT);
  pinMode(in4, OUTPUT);
  
  // Turn on motors
  digitalWrite(in1, LOW);
  digitalWrite(in2, HIGH);  
  digitalWrite(in3, LOW);
  digitalWrite(in4, HIGH);
  pinMode(LED, OUTPUT);

  // Kick starter for the motor
  analogWrite(enA, 255);
  delay(20);
  
  // For autosaving
  lastSave = millis(); // inital start

  Serial.begin(9600);
  Serial.println("CLEARRANGE,A,2,H,1000000"); // trick to get rid of AM-PM
  mySerial.begin(19200); // for data streaming from DO logger 
}


void loop(){
  pumpControl(); // to control a pump
  motorControl(); // to regulate motor speed
  buttonEvents(); // to identify button actions
  displayUpdate(); // to show motor information
  loggerStream(); // to receive data from logger
  autoSave(); // to save data in Excel every minute
}
 

void pumpControl(){
  if (PHASE_SWITCH_METHOD == "constant_phase_period"){
    unsigned long currentTime_pump = millis();
    if(currentTime_pump - previousTime_pump <= FLUSH*1000UL){
      // set pin 3 OFF to turn off the relay,
      F = f + PERIOD;
      analogWrite(enB, 255);   // so pumps start working again.
      digitalWrite(LED, HIGH);
      PHASE = F;
    }
    else if(currentTime_pump - previousTime_pump > FLUSH*1000UL && 
            currentTime_pump - previousTime_pump <= MEASUREMENT*1000UL 
                                                      + FLUSH*1000UL){
      digitalWrite(enB, 0); // set pin 3 ON to activate the relay,
                                // so pumps stop working
        // blinking LED during Measurement Phase
        M = m + PERIOD;
        if(currentTime_pump % 1000UL <= 800UL){
          digitalWrite(LED, LOW);
        }
        else{
          digitalWrite(LED, HIGH);
        }
        PHASE = M;
    }
    else{
      previousTime_pump = currentTime_pump;
      PERIOD++;
    }
  }

  else if(PHASE_SWITCH_METHOD == "saturation_threshold"){
    unsigned long currentTime_pump = millis();

    if((SATURATION <= LOW_SATURATION_THRESHOLD || HIGH_SATURATION_REACHED == false) && DO != 0){
      F = f + PERIOD;
      analogWrite(enB, 255);   // so pumps start working again.
      digitalWrite(LED, HIGH);
      String previous_phase = PHASE;
      PHASE = F;  
      if(PHASE[0] != previous_phase[0]){
        previousTime_pump = currentTime_pump;
      }
      if(SATURATION > HIGH_SATURATION_THRESHOLD){
        HIGH_SATURATION_REACHED = true;
      }
      else{
        HIGH_SATURATION_REACHED = false;
      }
    }
    else if((SATURATION > LOW_SATURATION_THRESHOLD && HIGH_SATURATION_REACHED == true) && DO != 0){
      digitalWrite(enB, 0); // set pin 3 ON to activate the relay,
                              // so pumps stop working
      // blinking LED during Measurement Phase
      M = m + PERIOD;
      if(currentTime_pump % 1000UL <= 800UL){
        digitalWrite(LED, LOW);
      }
      else{
        digitalWrite(LED, HIGH);
      }
      String previous_phase = PHASE;
      PHASE = M;
      if(PHASE[0] != previous_phase[0]){
        previousTime_pump = currentTime_pump;
        PERIOD++;
      }
    }
    else{
      Serial.println("SOMETHING IS WRONG HERE !!!");
    }
  }

  else{
    Serial.println("Choose the phase switch method in USER INTERFACE: lines 5-17");
  }
}


void motorControl(){
  // map actual values (cm/s) to raw (bits 0...255)
  float raw = FmultiMap(VELOCITY[i], in, out, sizeof in/sizeof *in);

  unsigned long currentTime_motor = millis();
  if(currentTime_motor - previousTime_motor <= LENGTH[i]*1000UL){
    analogWrite(enA, raw);
    TIMER = (currentTime_motor - previousTime_motor)/1000UL;
  }
  else{
    i++;
    previousTime_motor = currentTime_motor;
    TIMER = 0UL;
  }
  
  // Number of elements in an array
  if(i >= sizeof LENGTH/sizeof *LENGTH){
    i = 0;
  }
}


void buttonEvents(){
  // note, the logic is inversed here due to an internal pull-up resistor
  if (digitalRead(BUTTON_GREEN) != HIGH) {
		if (buttonActive == false) {
			buttonActive = true;
			buttonTimer = millis();
		}
    button1Active = true;
	}

	if (digitalRead(BUTTON_RED) != HIGH) {
		if (buttonActive == false) {
			buttonActive = true;
			buttonTimer = millis();
		}
		button2Active = true;
	}
  delay(50);

	if ((buttonActive == true) && (digitalRead(BUTTON_GREEN) != LOW) && (digitalRead(BUTTON_RED) != LOW)) {
		if(longPressActive == true) {
			longPressActive = false;
		} 
    else{
			if((button1Active == true) && (button2Active == true)) {
				Serial.println("Short press custom mode: programm it yourself");
        } 
      else if((button1Active == true) && (button2Active == false)) {
		  // CASE1: short press -> reverse motor for a several seconds
        unsigned long previousTime_motor = millis();
        TIMER = 0;
        i = i - 1;
        }
			else if((button1Active == false) && (button2Active == true)) {
		  // CASE2: short press -> reverse motor for a several seconds
        unsigned long previousTime_motor = millis();
        TIMER = 0;
        i = i + 1;
			}
      else{
      }
		}
		buttonActive = false;
		button1Active = false;
		button2Active = false;
	}

  if ((buttonActive == true) && (millis() - buttonTimer > buttonTime) && (longPressActive == false)) {
		longPressActive = true;
		if ((button1Active == true) && (button2Active == true)) {
			Serial.println("Long press custom mode: programm it yourself");
      }
		else if((button1Active == true) && (button2Active == false)) {
      // CASE3: long press -> reverse motor
      reverseMotor1 = !reverseMotor1; //motor IN1
      reverseMotor2 = !reverseMotor2; //motor IN2
      for (int j = VELOCITY[i]; j >= 0; j = j-10){  //soft reverse
          analogWrite(enA, j);
          delay(5);
        }
      digitalWrite(in1, reverseMotor1);
      digitalWrite(in2, reverseMotor2);

      analogWrite(enA, 123);
      delay(50);
      }
    else if((button1Active == false) && (button2Active == true)) {
      // CASE4: long press -> 2.5 hour pause
      for (int j = VELOCITY[i]; j >= VELOCITY[0]; j = j-1){  //soft reverse
        analogWrite(enA, j);
        delay(20);
        }
      i = 0;
      VELOCITY[0] = {5};
      LENGTH[0] = {9999};
      }
		else{
		}
	}
}


void displayUpdate() {
  unsigned long currentTime_display = millis();
  if(currentTime_display - previousTime_display > 1000UL){
    oled.setCursor(2,0);
    oled.set2X();
    oled.print("Velocity");
    if(reverseMotor1 == true){
      oled.setCursor(115,0);
      oled.print("R");
    }
    else{
      oled.setCursor(115,0);
      oled.print("   ");
    }

    oled.setCursor(2,3);
    oled.print((VELOCITY[i]));
    oled.setCursor(66,3);
    oled.print(" cm/s");

    oled.setCursor(2,6);
    oled.set1X();
    oled.print("NOW  ");
    oled.print(LENGTH[i]);
    oled.print("s   ");
    oled.setCursor(66,6);
    int percent_bar = (TIMER)/LENGTH[i]*100;
    int dash_bar = percent_bar/10;
    for(int k = 0; k <= dash_bar; k++){
      oled.print("#");
    }
    for(int j = dash_bar; j >= dash_bar && j < 10; j++){
      oled.print(" ");
    }

    oled.setCursor(2,7);
    oled.set1X();
    oled.print("NEXT ");
    oled.print(LENGTH[i+1]);
    oled.print("s   ");
    oled.setCursor(66,7);
    oled.print((VELOCITY[i+1]));
    oled.setCursor(102,7);
    oled.print("cm/s");

    previousTime_display = currentTime_display;
    }
  }


void loggerStream(){
  unsigned long currentTime_logger = millis();
  if(currentTime_logger - previousTime_logger > 1000UL){
    mySerial.println("MEA 1 7");

    int k = 0;
    while (mySerial.available() > 0) {
      int inByte = mySerial.read();
      Serial.write(inByte);
      charArr[k] = inByte;
      k++;
    }
    Serial.println();

    byte index = 0;
    ptr = strtok(charArr, " ");  // delimiters space and comma
    while (ptr != NULL)
    {
        strings[index] = ptr;
        index++;
        ptr = strtok(NULL, " ");
    }

    String a = (strings[5]); // (umol*32)/1000) -> mg/L
    DO = (32 * a.toFloat())/1000000;

    String b = (strings[7]); // %
    SATURATION = (b.toFloat())/1000;

    String c = (strings[8]); // C
    TEMPERATURE = (c.toFloat())/1000;

    String d = (strings[12]); // mbar
    PRESSURE = (d.toFloat());
    // quick fix for a randomly cut pressure value due to a buffer 
    // limitation in the UART communication (i.e. 64 bytes)
    if (PRESSURE > 500 && PRESSURE < 1500){
      PRESSURE = (d.toFloat());
    }
    else if (PRESSURE > 5000 && PRESSURE < 15000){
      PRESSURE = (d.toFloat())/10;
    }
    else if (PRESSURE > 50000 && PRESSURE < 150000){
      PRESSURE = (d.toFloat())/100;
    }
    else if (PRESSURE > 500000 && PRESSURE < 1500000){
      PRESSURE = (d.toFloat())/1000;
    }
    else{
    }

    // Parse to PLX-DAQ
    if (TEMPERATURE != 0 && DO != 0 && PHASE != "M0"){
      Serial.println((String) "DATA,DATE,TIME," + (String) PHASE + (",") + TEMPERATURE + (",")
                            + DO + (",") + (VELOCITY[i]) + (",") + PRESSURE + (",") + SATURATION);
    }

    previousTime_logger = currentTime_logger;
  }
}


void autoSave(){
  if (millis() - lastSave >= 60000) { // one minute auto save
    Serial.println((String) "SAVEWORKBOOK");
    lastSave = millis();
    //Serial.println((String) "DONE"); // flushing the serial port in Excel
  }
}


// Originally from: https://playground.arduino.cc/Main/MultiMap
float FmultiMap(float val, float * _in, float * _out, uint8_t size){
  // take care the value is within range
  // val = constrain(val, _in[0], _in[size-1]);
  if (val <= _in[0]) return _out[0];
  if (val >= _in[size-1]) return _out[size-1];

  // search right interval
  uint8_t pos = 1;  // _in[0] allready tested
  while(val > _in[pos]) pos++;

  // this will handle all exact "points" in the _in array
  if (val == _in[pos]) return _out[pos];

  // interpolate in the right segment for the rest
  return (val - _in[pos-1]) * (_out[pos] - _out[pos-1]) / 
          (_in[pos] - _in[pos-1]) + _out[pos-1];
}


/* REFERENCES:
1. L298n: https://dronebotworkshop.com/dc-motors-l298n-h-bridge/
2. Multimap: https://playground.arduino.cc/Main/MultiMap/
3. Buttons: https://www.instructables.com/Arduino-Dual-Function-Button-Long-PressShort-Press/
   (a mistake in schematics: the orange wire should be in line #5)
4. Event-based programming: ... //// ADD HERE!
5. Display library, i.e. 'AvrI2c128x64.ino' example: https://github.com/greiman/SSD1306Ascii
6. Serial protocol for Pyroscience: ... //// ADD HERE!
7. SoftwareSerial Library documentation: https://docs.arduino.cc/learn/built-in-libraries/software-serial/ */

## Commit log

2022-01-21 The SwimResp sketch for two channels without buttons
2022-01-26 Add the button settings
2022-01-26 Test short- and long button pressing
    [SwimResp.ino]
2023-09-01 Add two photos of the prototype in README.md
2024-04-21 Update code for the first prototype
    Major revision of code for the assembled swim tunnel with an
    embedded motor controller. Pinout map is updated, motor and
    pump control are improved, minor changes related to performance.
2024-04-23 Integrate i2c display, add logo, adjust layout
2024-04-24 Implement button logic for manual motor control
2024-04-25 Add function for data parsing from Pyroscience Pico
    The code works well in isolation, but not inside main program.
2024-04-27 Replace Adafruit library for display
    [SwimResp.ino]
2024-08-01 Major update of SwimResp.ino working with macros
    - Enable data stream from .ino to .xlsm
    - Create new phase switch method based on DO threshold values
    - Add regular autosaves for Excel through PLX-DAQ's API and Arduino
    - Write callibration description in the User Interface section
    - Remove obsolete code, standardize variable names
2026-07-14 Create host Excel app/template
    [SwimResp_template.xlsm]
2026-07-15 Add wiring diagram and build guide template
2026-07-28 Create cad files and blueprints
    [SwimResp_enclosure_assembly.step, SwimResp_enclosure_base.step, SwimResp_enclosure_base.stl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]
2026-07-30 Create schematics and updated wiring diagram
2026-08-02 Add BOM section to SwimResp Build Guide
2026-08-08 Write assembly instructions for SwimResp
2026-08-09 Fix screen missalignment of SH1106 OLED driver
    [SwimResp.ino]
2026-08-09 Move notes about 3.3 V logic notes into a separate file
